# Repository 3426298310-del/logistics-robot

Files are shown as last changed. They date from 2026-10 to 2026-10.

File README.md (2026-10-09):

# Logistics Robot — Mechanical Design

HKU DASE7503 Robotic Systems Integration · Group 8 · Work in progress

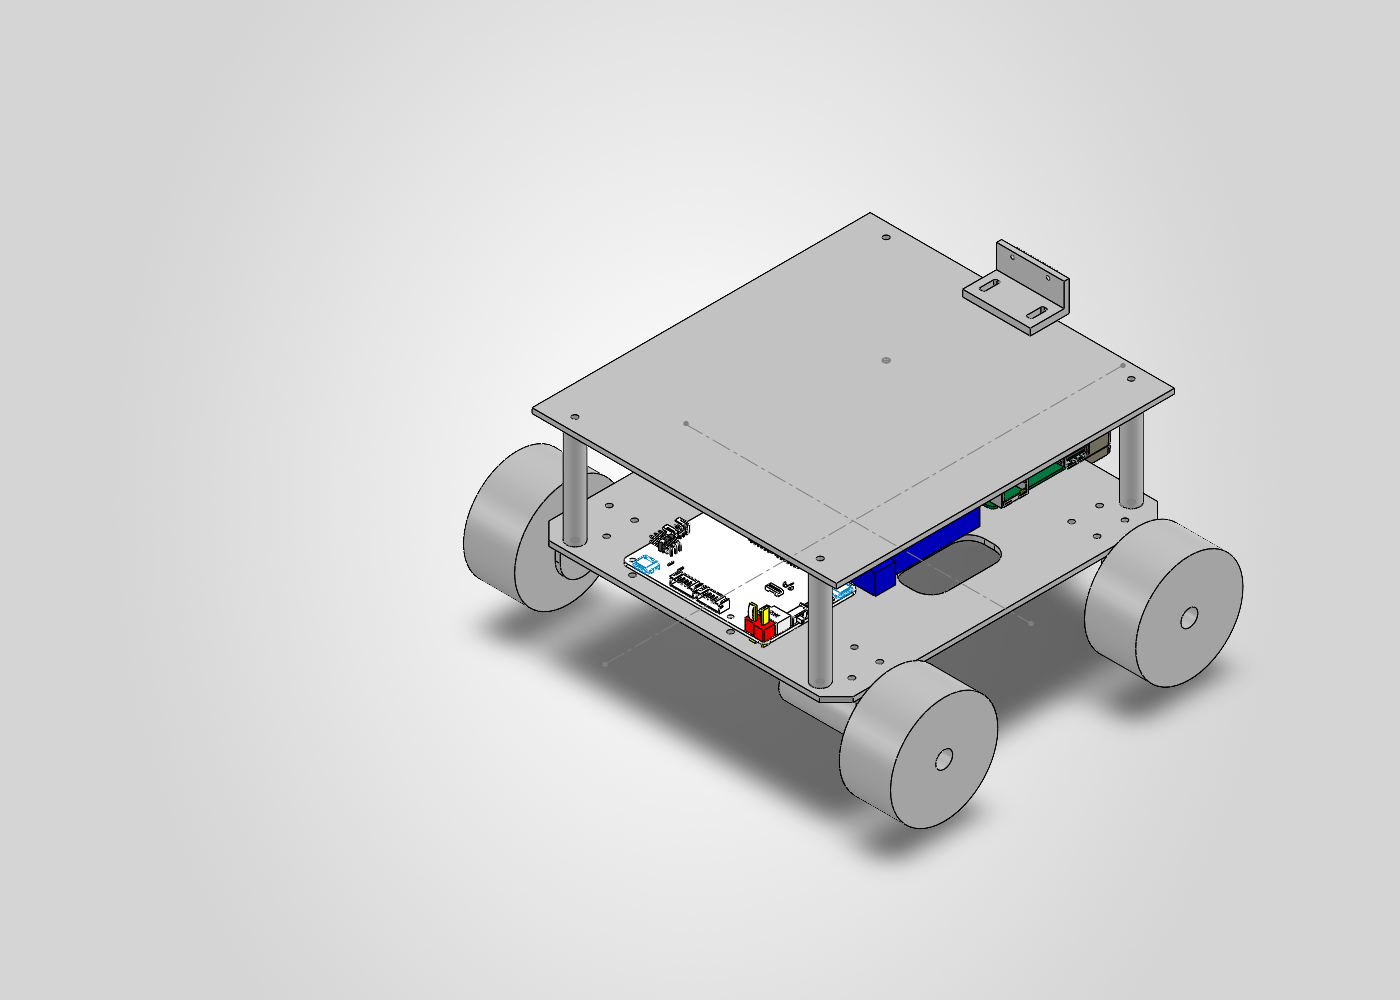
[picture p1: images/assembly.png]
SolidWorks assembly


## 项目与个人贡献

物流机器人小组项目，目标为移动、托举及运输货物。本仓库记录王正的机械设计与硬件集成工作。根据本人确认，独立重建整车 SolidWorks 模型，完成底盘、电机支架、轮组、双层板、立柱和相机安装结构的布局，结合硬件测量准备加工文件。运动控制、视觉、雷达识别与路径规划由其他组员负责，不属于本人的软件成果。

## 当前进度（2026-10-09）

- 已完成：整车机械建模、硬件布局、亚克力板 DXF 加工图。
- CAD 检查：25 个组件正常加载，实体外廓约 252.60 × 240.75 × 135.50 mm；2026-10-07 的检查未检测到组件间实体干涉。
- 进行中：加工准备与实体搭建。激光切割尚未完成。
- 尚未验证：完整实车运动、负载搬运、举升机构、视觉与路径规划。

## 文件

| 路径 | 内容 |
|---|---|
| `cad/solidworks/` | 原生装配、零件及雷达 STEP 参考模型 |
| `fabrication/底板.DXF` | 底板二维加工图，外廓 180 × 236.5 mm |
| `fabrication/fix_camera.STL` | 相机支架打印候选文件，尚未验证与装配内同名零件一致 |
| `docs/design-review.md` | 尺寸、装配检查和待解决问题 |
| `docs/sources-and-scope.md` | 模型来源、个人贡献及使用边界 |

## 打开模型

完整下载文件夹后，用兼容版本的 SolidWorks 打开 `cad/solidworks/整体.SLDASM`，保持零件文件在同一目录。原文件由 SolidWorks 2026 环境检查；不同版本兼容性需核对。雷达以 STEP 导入，原装配引用曾解析到临时目录；若重新打开提示缺失，应从同目录的 `MS200_X1_20221110.stp` 重新定位/导入，不应认为本包已经通过异机重开验证。

## 加工与尺寸边界

DXF 为二维图，需向加工方明确毫米单位、1:1 比例、材料和板厚。当前 CAD 外廓处于用户提供的 300 × 300 × 180 mm 限制内，但没有计入未知线缆、紧固件外伸与举升后的高度。CAD 无干涉不能证明承载能力或实车运行可靠性。

不包含课程 PDF、私人简历、联系方式或开发过程中的临时文件。第三方参考模型保留其原始权利；本仓库不对这些模型授予统一开源许可，相关来源与使用边界见 docs/sources-and-scope.md。

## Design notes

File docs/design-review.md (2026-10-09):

# Mechanical design review

Check performed on 2026-10-07 in SolidWorks. No source geometry was modified during the review.

| Item | Model measurement |
|---|---|
| Assembly | 25 resolved components |
| Overall width × length × height | 252.60 × 240.75 × 135.50 mm |
| Base plate | 180 × 236.50 × 3 mm |
| Upper plate | 180 × 200 × 3 mm |
| Layer clearance | 60 mm |
| Wheel | Ø63.50 × 30.30 mm, simplified envelope |
| LiDAR ground clearance | 18.50 mm, assuming wheel envelope touches flat ground |
| Interference detection | 0 detected; coincident contacts and internal multibody interference excluded |

底板四角实体孔已经补齐。待确认：轮与电机之间约8.5mm轴向间距的适配器及锁紧方式；电控隔离柱、紧固件；相机镜头与排线空间；电池模型含外伸结构的82.5mm包络与72.5mm主体实测区别；加工公差和材料承载。不得将本报告视为实车验收。

DXF 检查：180 × 236.5 mm外廓，32个圆形轮廓；四组Ø3.2mm孔的组内孔距15 × 16.5mm，另有4个Ø3.3mm孔，电控孔距58 × 49mm。实际用途和支架匹配须在加工前确认。

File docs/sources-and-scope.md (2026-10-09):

# Sources and scope

Owner: WANG Zheng. Group: HKU DASE7503 Group 8.

个人贡献按2026-10-09本人确认记录：独立重建整车机械模型；负责硬件布局与加工准备。不是宣称自行设计厂家电子设备，也不将团队软件工作归为个人成果。

树莓派、MicroROS控制板和MS200雷达属于第三方硬件参考模型。具体下载来源和再分发许可尚待补充，不能统一授予开源许可。参考网站：https://www.raspberrypi.com/ ，https://www.yahboom.net/study/MicroROS-Board ，https://www.yahboom.net/study/MS200 。本仓库未逐项重新核实网页授权。

课程材料与老师样机图片不随仓库发布。个人简历只保存在本地交付目录。制造及实车功能仍在推进，未声称已完成激光切割或自主搬运。

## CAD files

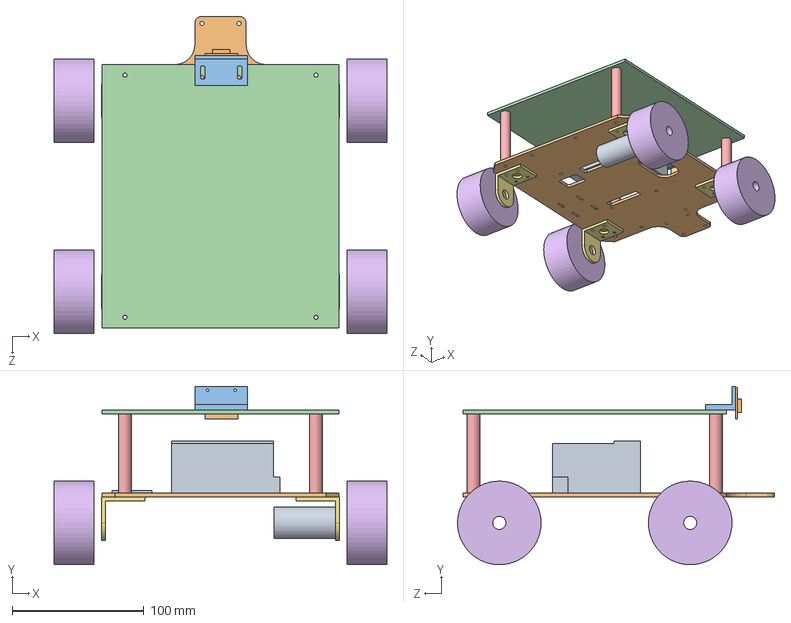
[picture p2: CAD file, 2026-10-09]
cad/solidworks/整体.SLDASM
252.6 x 135.5 x 240.7 mm
底板
Battery
lidar板
motor_fix x 4
轮 x 4
abs柱 x 4
頂板
fix_camera
camera板
motor

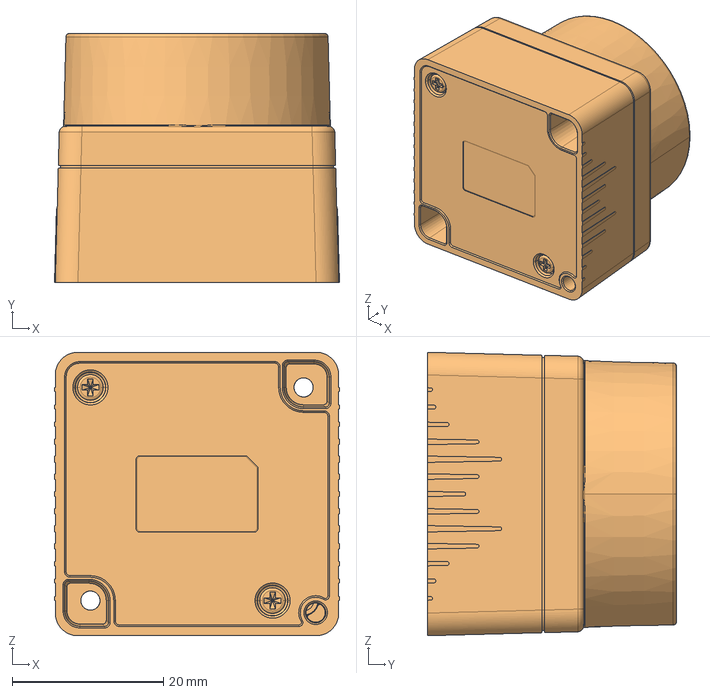
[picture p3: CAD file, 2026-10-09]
cad/solidworks/MS200_X1_20221110.stp
37.7 x 33.0 x 37.5 mm

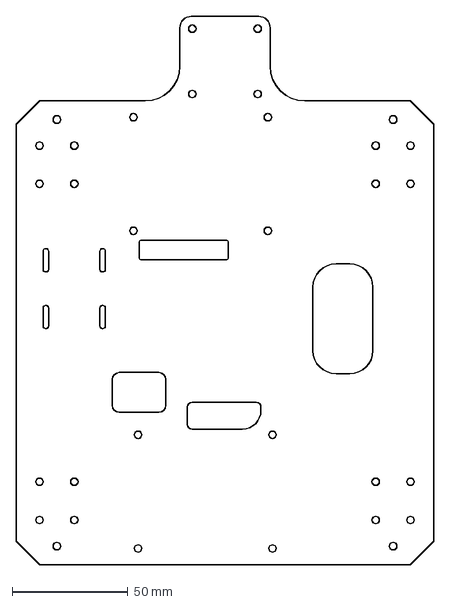
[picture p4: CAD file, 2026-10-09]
fabrication/底板.DXF
180.0 x 236.5 mm

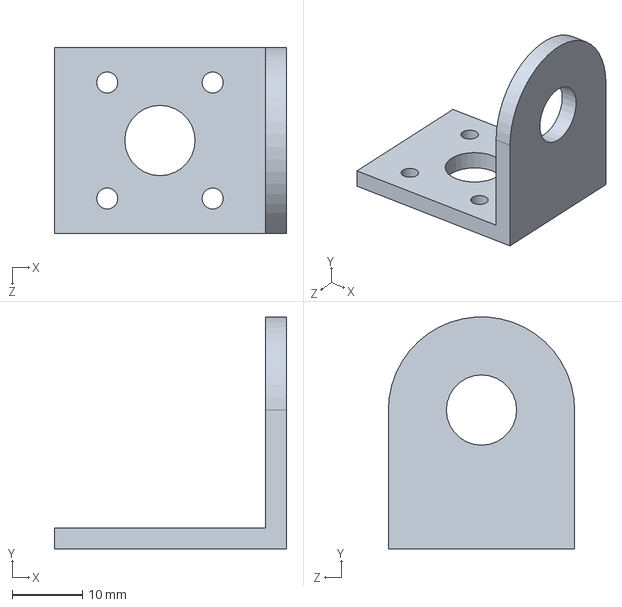
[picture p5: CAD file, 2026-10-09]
cad/solidworks/motor_fix.SLDPRT
33.0 x 33.0 x 26.5 mm

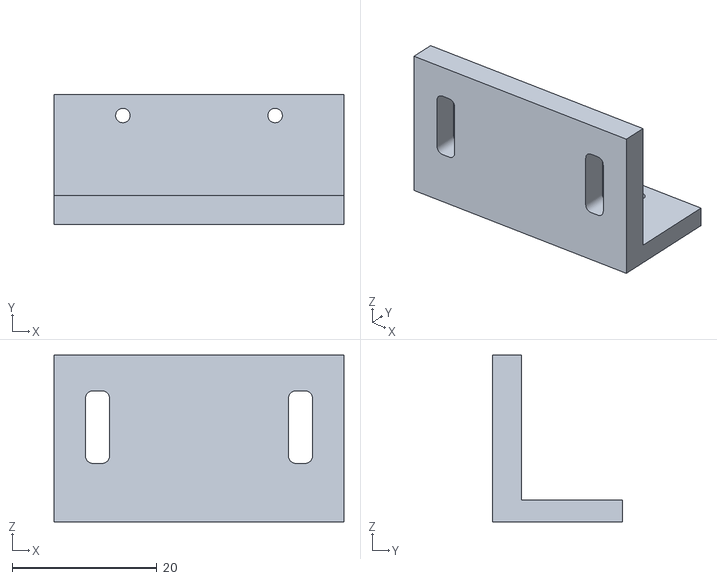
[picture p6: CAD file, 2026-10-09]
fabrication/fix_camera.STL
40.0 x 18.0 x 23.0

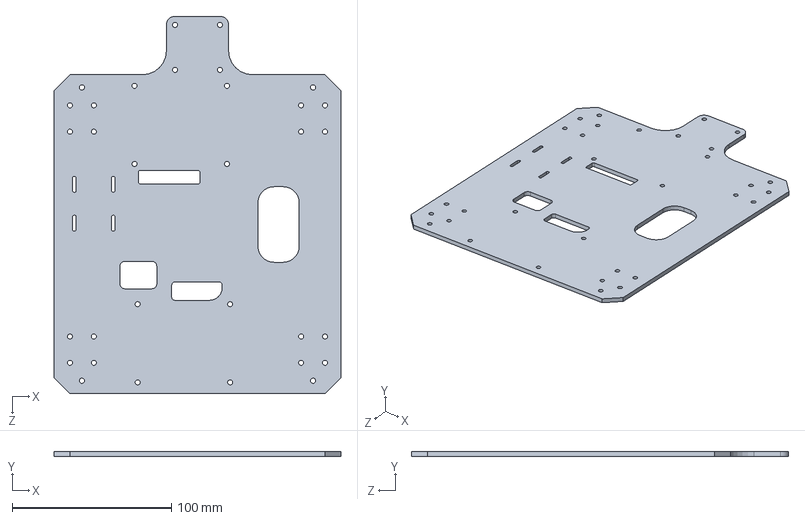
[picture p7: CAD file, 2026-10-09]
cad/solidworks/底板.SLDPRT
180.0 x 3.00 x 236.5 mm

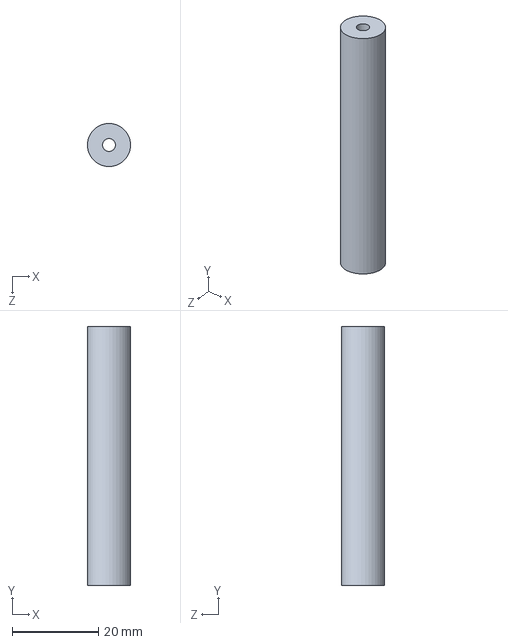
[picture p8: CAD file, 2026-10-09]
cad/solidworks/abs柱.SLDPRT
9.97 x 60.0 x 10.0 mm

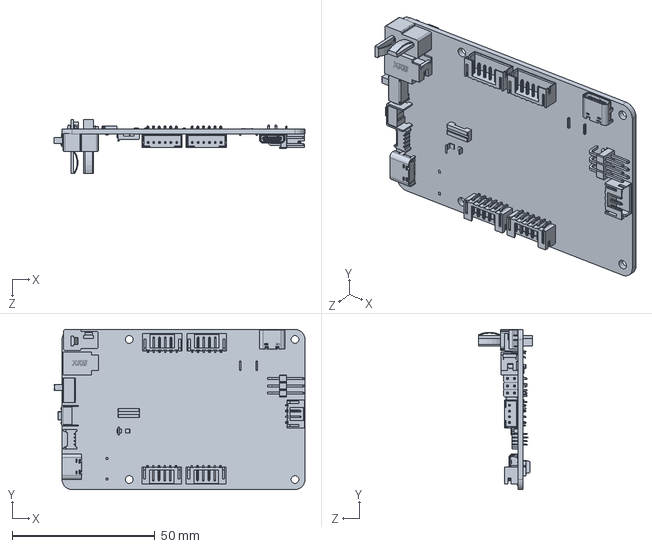
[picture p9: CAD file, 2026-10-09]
cad/solidworks/MicroROS_Control_Board_defeature.SLDPRT
87.8 x 56.0 x 19.0 mm

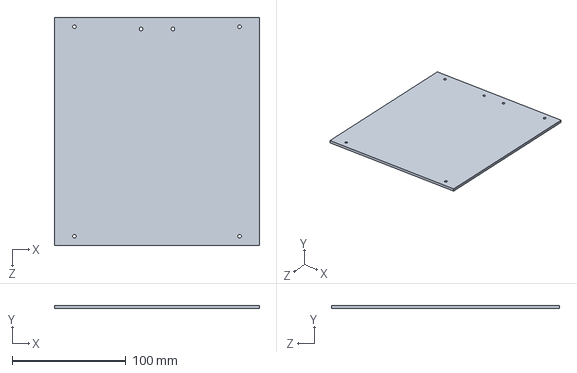
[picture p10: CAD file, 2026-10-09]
cad/solidworks/頂板.SLDPRT
180.0 x 3.00 x 200.0 mm

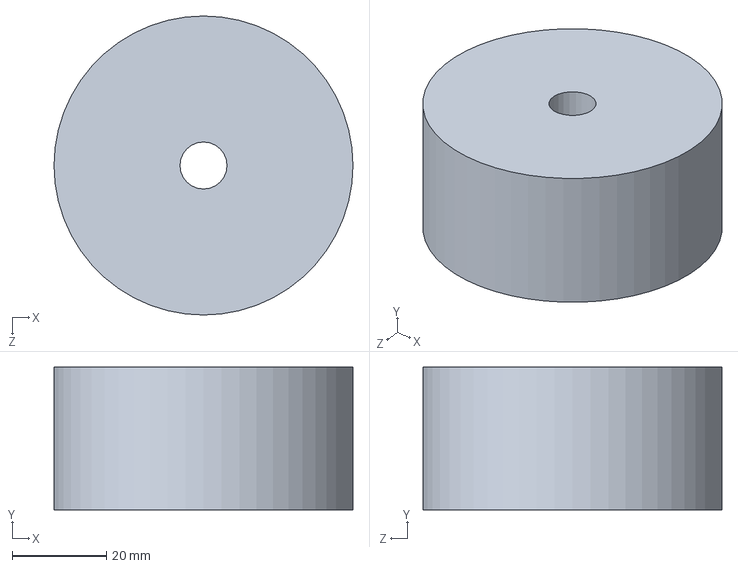
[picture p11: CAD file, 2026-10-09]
cad/solidworks/轮.SLDPRT
63.5 x 30.3 x 63.5 mm

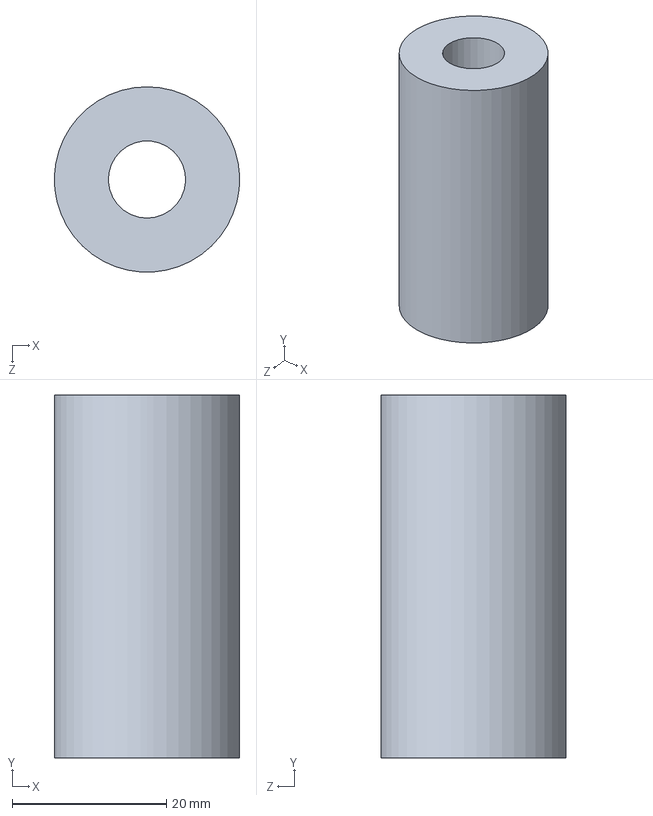
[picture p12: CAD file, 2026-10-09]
cad/solidworks/motor.SLDPRT
24.0 x 47.0 x 24.0 mm

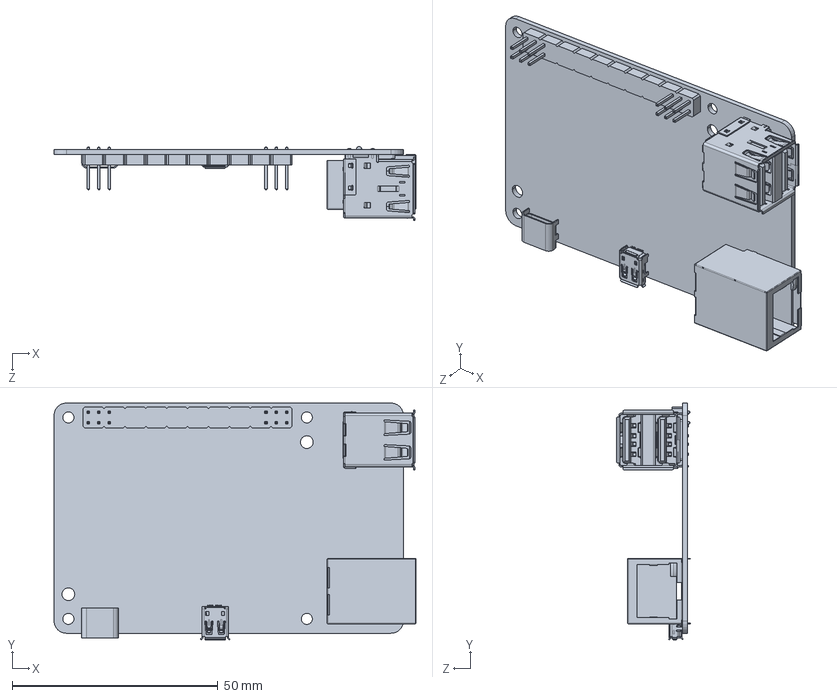
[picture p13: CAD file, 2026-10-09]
cad/solidworks/rpi-5b_no_graphics_1_defeature.SLDPRT
88.1 x 57.6 x 18.0 mm

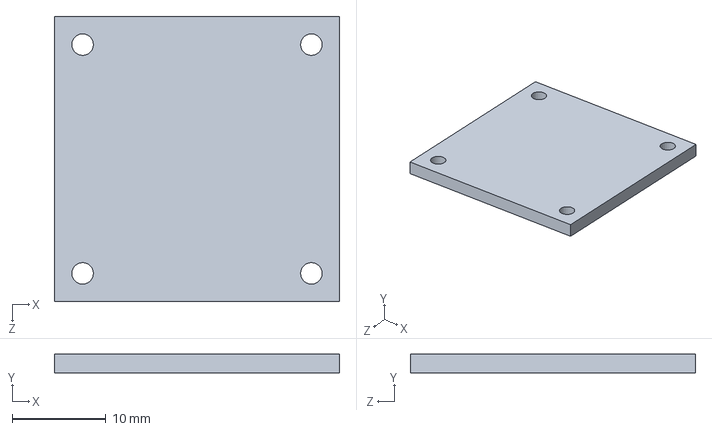
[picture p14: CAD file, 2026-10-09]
cad/solidworks/lidar板.SLDPRT
30.4 x 2.00 x 30.4 mm

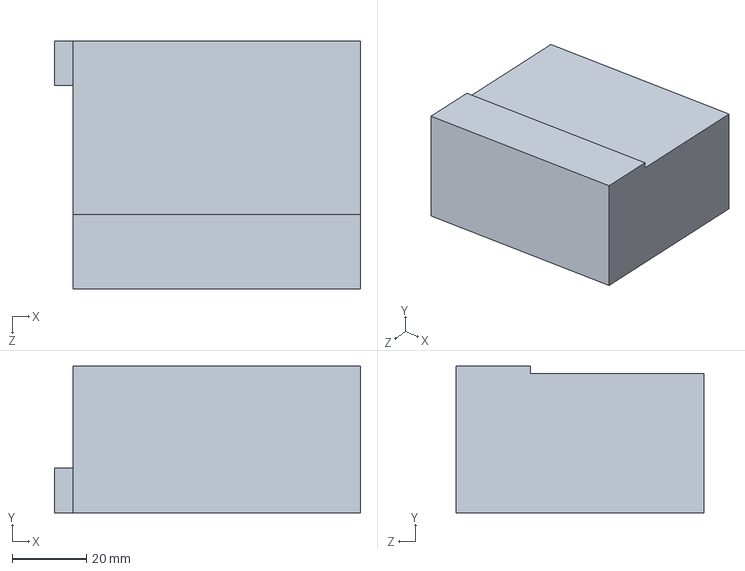
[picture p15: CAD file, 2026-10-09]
cad/solidworks/Battery.SLDPRT
82.5 x 39.5 x 66.8 mm

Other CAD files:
cad/solidworks/fix_camera.SLDPRT
cad/solidworks/camera板.SLDPRT

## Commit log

2026-10-09 Document logistics robot mechanical design and fabrication preparation
    [Battery.SLDPRT, MS200_X1_20221110.stp, MicroROS_Control_Board_defeature.SLDPRT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]
2026-10-09 Preserve exact CAD and fabrication file bytes
    [MS200_X1_20221110.stp, 底板.DXF]
2026-11-03 Replace beta CAD with final complete robot model
